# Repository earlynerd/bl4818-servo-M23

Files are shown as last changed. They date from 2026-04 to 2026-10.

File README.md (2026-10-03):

# BL4818 Brushless Servo Musical Actuator

This repository contains the electronics, embedded firmware, host software,
and browser players for a network of brushless servo percussion actuators.
The actuators use modified BL4818 motor-controller hardware, a Nuvoton M2003
microcontroller, hall sensing, and an MT6701 absolute encoder to move a mallet
with controlled timing and force.

The system is in active use: roughly 35 actuators have been built, and the
firmware plus MIDI player/server are working well. The software is much closer
to production-ready than the replication documentation, so this repository
should currently be treated as a proven project under documentation rather
than a turn-key kit.

## Watch and listen

This project makes much more sense with sound. Select the image or the link
below to hear ten actuators perform on a handpan-style tongue drum.

**[▶ Play the 56-second performance video with sound](docs/video/handpan_video_h264.mp4)**

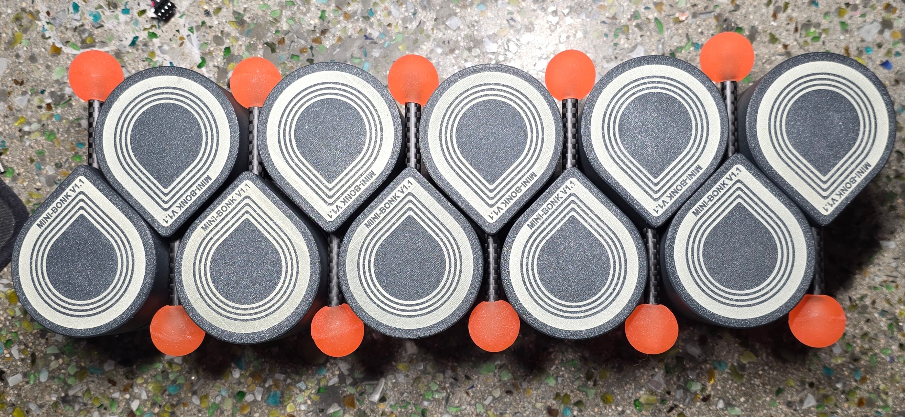
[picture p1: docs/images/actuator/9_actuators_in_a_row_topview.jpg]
Nine completed actuator bodies and mallets viewed from above
 

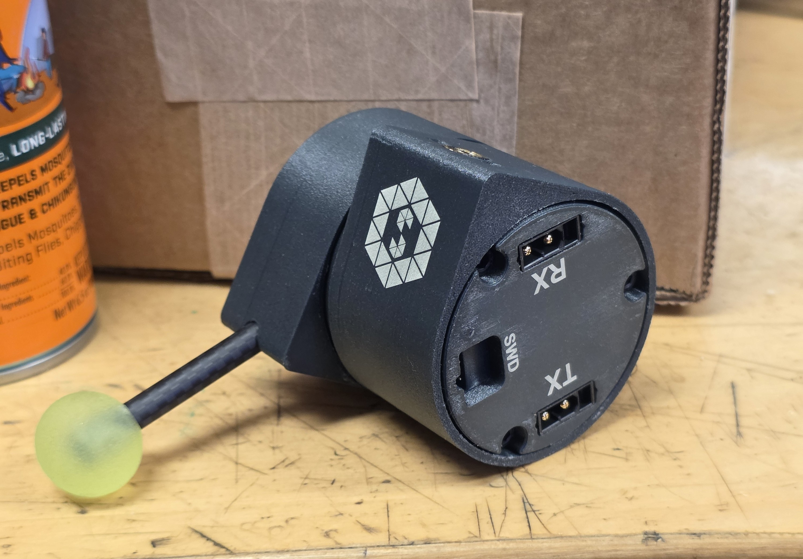
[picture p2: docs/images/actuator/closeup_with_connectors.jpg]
Close-up of an assembled actuator showing RX, TX, and SWD openings
 

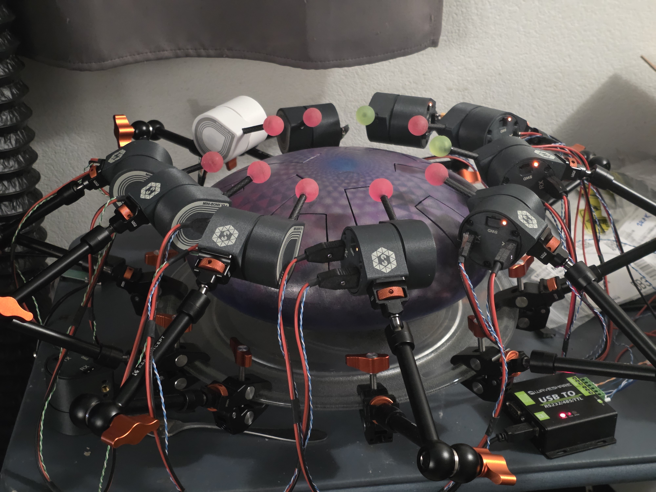
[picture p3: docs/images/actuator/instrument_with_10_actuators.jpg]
Ten brushless servo actuators installed around a tongue drum


Each self-contained actuator packages the modified BL4818 motor controller,
absolute encoder, power/data interface, and mallet mechanism inside the printed
shell. RX and TX connectors allow power and serial data to continue through the
actuator chain, while the recessed SWD port provides programming access.

## System overview

```mermaid
flowchart LR
    MIDI["MIDI file or browser player"] --> HTTP["Python MIDI server"]
    HTTP --> IFACE["USB serial / interface hardware"]
    IFACE --> A0["Actuator 0"]
    A0 --> A1["Actuator 1"]
    A1 --> AN["More actuators"]
    AN --> IFACE
```

The Python server owns the serial port and serves the browser UI. It enumerates
the actuator ring, maps MIDI pitches to actuator addresses, schedules strikes,
compensates for measured mechanical latency, and can build then deploy APROM
updates through the permanent LDROM loaders without releasing the serial port.
The updater and synchronized chord scheduler are hardware-validated on the
14-actuator handpan ring.
Each actuator closes its own
current, velocity, and position loops and runs the homing/strike state machine.
The current protocol uses a four-bit address and supports up to 16 actuators per
ring.

## What is in this repository

- `src/` and `include/`: M2003 bare-metal firmware.
- `scripts/`: ring-bus client, MIDI server, tuning, measurement, and demo tools.
- `player/`: browser-based MIDI player, looper, and tongue-drum player.
- `pcb/`: KiCad electronics plus current mechanical/fabrication exports.
- `mechanical/`: SolidWorks source CAD and STEP exports for the actuator shell,
  mallet holder, and interface-board reference model.
- `docs/`: replication notes, hardware references, debug history, and design notes.
- `protocol.md`: byte-level Ring Bus Protocol v2 specification.
- `midi_server_api.md`: HTTP API for integrations and custom players.

See [Repository map](docs/repository-map.md) for a guided tour.

## Quick software start

The firmware builds on Windows and POSIX hosts, including Raspbian. Its Makefile
expects GNU Make and the Arm GNU toolchain in `PATH`. Initial SWD provisioning
still uses the PowerShell/J-Link scripts and is therefore Windows-oriented.

### 1. Install host dependencies

Install Python 3.10 or newer, then from the repository root run:

```powershell
py -m venv .venv
.\.venv\Scripts\Activate.ps1
py -m pip install -r requirements.txt
```

### 2. Build the firmware

Install `arm-none-eabi-gcc` and GNU Make, then run:

```powershell
make
```

The main output is `build/m2003-motor.bin`. Generate the complete J-Link
payload (application, commit manifest, permanent LDROM loader, and read-only
CONFIG capture) with:

```powershell
powershell -File scripts/build-jlink.ps1
```

Generation does not contact hardware or change CONFIG. The stable Gen1 ring
updater, its recovery evidence, and its completed 14-actuator validation are
documented in [Ring firmware update](docs/firmware-update.md). The LDROM loader
is now maintenance-only; no further Gen1 loader features are planned.

### 3. Flash an actuator

Connect the programmer over SWD and run:

```powershell
powershell -File scripts/flash-jlink.ps1
```

For J-Link V9.58 or newer, use the faster native M2003FC1AE flash loader:

```powershell
powershell -ExecutionPolicy Bypass -File scripts/flash-jlink.ps1 -NativeFlash
```

Add `-SkipBuild` to reuse the generated artifacts, or `-GenerateOnly` to build
them without contacting hardware. Native mode retains the CONFIG preservation,
commit-last manifest, and physical verification described below. Omitting
`-NativeFlash` retains the original per-word programming method.

This standard command first records CONFIG0..2, programs and byte-verifies
APROM, its manifest, and LDROM, then preserves the existing configuration while
selecting LDROM-first boot. It refuses automatic CONFIG changes on a locked or
unexpected security configuration. Disconnect motor power while changing
wiring or attaching the programmer; a servo actuator can move unexpectedly
during bring-up.

### 4. Start the MIDI player

Connect the interface serial port to a powered actuator ring and run:

```powershell
py scripts/ring_midi_server.py -p COM7 --library-dir C:\path\to\midi-library
```

Open <http://localhost:8765/>. Enumerate the ring, home the actuators, and assign
a MIDI pitch to each slot before playing a file. Use the instrument selector
to save and switch named pitch maps and player settings. Profiles are stored locally in
`instruments.json` and are intentionally not committed. An existing
`mapping.json` is imported as the Default profile.

For multiple rings, use one USB adapter per ring (at most 16 actuators each):

```powershell
py scripts/ring_midi_server.py --ring jameson=COM29,10 --ring retuned=COM48,10
```

The player provides a saved-instrument selector for each ring and shared playback
controls. See [multiple-ring setup](docs/host-software.md#multiple-rings-on-one-server)
for profile persistence and slot routing. Firmware updates still use single-ring mode.

For a first hardware check without the browser:

```powershell
py scripts/ring_tool.py -p COM7 enumerate
py scripts/ring_tool.py -p COM7 status 0
```

Run `py scripts/ring_tool.py --help` for the complete command list.

## Documentation

- [Replication guide](docs/replication-guide.md): staged path from hardware to a playing ring.
- [Hardware guide](docs/hardware.md): current BL4818 modification and actuator assembly architecture.
- [Performance video](docs/video/handpan_video_h264.mp4): ten actuators playing with sound.
- [Firmware guide](docs/firmware.md): architecture, build, flash, and module boundaries.
- [Ring firmware update](docs/firmware-update.md): stable LDROM recovery design, flash layout, operation, and validation record.
- [Host software guide](docs/host-software.md): server, browser players, and bench tools.
- [Replication status](docs/replication-status.md): what is reproducible now and what still needs source material.
- [Ring Bus Protocol v2](protocol.md): serial packet and command specification.
- [MIDI server HTTP API](midi_server_api.md): integration API.
- [Design decisions](Decisions.md) and [debug log](DebugLog.md): engineering history.

## Replication status and safety

The repository does not yet contain enough verified information for a new
builder to safely reproduce the complete actuator without assistance. In
particular, power-system limits, connector pinouts, a released BOM, mechanical
assembly dimensions, and a photographed bring-up procedure still need to be
documented. Those gaps are tracked explicitly in
[Replication status](docs/replication-status.md); unknown values are not guessed
in the guides.

This project drives a fast moving mechanism at several amps. Use a current-
limited supply during bring-up, keep hands and instruments clear of the mallet,
provide a physical power disconnect, and test one actuator before assembling a
ring.

## License

No project-wide license has been selected yet. Until one is added, the source
is visible for evaluation but normal open-source reuse permissions have not
been granted. A license should be chosen before presenting the repository as a
fully replicable open-source project; third-party code under `CMSIS/`,
`Library/`, and `RTT/` retains its own notices and terms.

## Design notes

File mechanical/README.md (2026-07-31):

# Mechanical design files

This directory is the maintained source for the actuator enclosure and moving
parts. The current files were created/exported with SolidWorks 2026. Keep native
CAD separate from neutral and print-ready exports so another builder can both
reproduce the proven design and modify it responsibly.

## Directory layout

- `source/`: native SolidWorks assembly/part files and linked components.
- `print-files/`: neutral STEP exports and, when available, revisioned STL or
  3MF files in the verified print orientation.
- Add `drawings/` if dimensioned PDFs, DXFs, or inspection drawings become
  available.

The expected part set includes the three-piece shell, the mallet holder that
slides over the motor bell, and the internal-shaft encoder magnet holder.

## Current file manifest

| File | Role |
| --- | --- |
| `source/actuator.SLDASM` | Top-level actuator assembly |
| `source/base.SLDPRT` | Main motor-side enclosure/base |
| `source/encodercover.SLDPRT` | Rear encoder/interface-board cover |
| `source/interface_pcb.SLDPRT` | Mechanical reference model for the custom PCB |
| `source/mallet_holder.SLDPRT` | Holder that slides over the motor bell |
| `print-files/base.STEP` | AP214 neutral export of the base |
| `print-files/encodercover.STEP` | AP214 neutral export of the encoder cover |
| `print-files/mallet_holder.STEP` | AP214 neutral export of the mallet holder |

The STEP headers identify SolidWorks 2026 and `SwSTEP 2.0`. Before calling this
a complete printable release, add or identify the magnet-holder and remaining
shell component if they are separate parts, verify that the assembly opens
without missing external references, and publish tested STL/3MF orientations or
explicit slicing instructions.

## Release information to include

For each known-good mechanical release, record:

- design/revision name and matching electronics revision;
- native CAD application and version;
- units and export tolerance;
- printer, material, nozzle, layer height, wall count, and infill;
- required supports and print orientation;
- heat-set inserts, screws, bearings, magnets, adhesives, and other hardware;
- critical fits, clearances, and post-processing;
- magnet dimensions, polarity, retention method, and MT6701 air gap;
- mallet/linkage installation and safe travel limits; and
- photographs of the completed assembly.

Do not replace an older known-good export in place. Add a new revision so the
files used for an existing actuator batch remain recoverable.

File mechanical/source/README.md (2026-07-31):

# Editable CAD source

This folder currently contains the SolidWorks 2026 top-level actuator assembly
and native models for the base, encoder cover, interface PCB, and mallet holder.
Add any missing linked components needed to open `actuator.SLDASM` without
suppressed or unresolved references. Future magnet-holder or enclosure parts
should remain alongside the assembly source.

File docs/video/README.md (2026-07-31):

# Demonstration video

`handpan_video_h264.mp4` is a 56-second sound-enabled demonstration of ten
actuators playing the instrument. It was re-encoded with HandBrake and contains
H.264 (`avc1`) video and AAC (`mp4a`) audio markers for broad browser
compatibility. The file is linked prominently from the main README.

The committed MP4 is approximately 36 MB. If a stable GitHub user-attachment or
release-asset URL is added later, the README target can be changed to that URL
to avoid carrying future video revisions in normal Git history.

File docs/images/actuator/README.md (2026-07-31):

# Actuator documentation images

Store the maintained actuator, rework, wiring, and assembly photographs here.

## Current images

| File | Shows |
| --- | --- |
| `closeup_with_connectors.jpg` | Completed actuator and end cap with RX, TX, and SWD openings |
| `9_actuators_in_a_row_topview.jpg` | Nine finished bodies, printed covers, mallet arms, and heads |
| `instrument_with_10_actuators.jpg` | Ten actuators mounted around a tongue drum with cabling and serial interface visible |

New images should use descriptive names such as `actuator-r1-exploded.jpg` or
`bl4818-r1-ina180-rework-closeup.jpg` rather than camera-generated filenames.

Instructional images should have a caption in the referring document that
states the hardware revision, orientation, and what the reader should verify.
Keep original-resolution masters when practical; optimized web copies can be
added separately if repository size becomes a concern.

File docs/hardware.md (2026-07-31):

# Hardware guide

## Current hardware generation

The actuators built so far use a manually modified BL4818 integrated motor-
drive PCB. This is the known working hardware generation. A future board may
replace the complete BL4818 drive PCB as a more drop-in design, but that board
is not the current replication target.

The present retrofit has four main parts:

1. The BL4818 motor and integrated three-phase drive PCB.
2. Manual drive-board modifications for the replacement microcontroller,
   amplified shunt-current measurement, signal routing, and added cabling.
3. A custom encoder/interface PCB carrying the MT6701, local capacitance,
   power/data connectors, and programming connector.
4. A printed three-piece enclosure plus mallet and magnet holders.

## Manual BL4818 drive-board modifications

At a high level, the working modification consists of:

- removing the original onboard microcontroller and installing a Nuvoton M2003;
- mounting an INA180B2 current-shunt amplifier as a bodge over the existing
  shunt area;
- removing selected resistors and shorting selected positions to reroute or
  adapt the relevant signals;
- installing an additional cable assembly alongside the original BL4818 cable.

This list deliberately does not identify pads or resistor designators yet. The
modification is fine-pitch, electrically consequential work on a motor power
stage; it should not be attempted from prose alone. The released instructions
need annotated before/after photographs, reference designators, wire endpoints,
wire gauge, insulation/strain-relief details, and continuity checks.

### Microcontroller

The replacement target is confirmed as the Nuvoton M2003 Cortex-M23. The
firmware, compiler target, linker setup, pin mapping, and hardware documentation
should all use M2003/Cortex-M23 consistently. The exact orderable suffix and
package should be recorded in the released BOM.

## Custom encoder/interface PCB

Both the original BL4818 cable assembly and the added cable assembly plug into
the custom board at the back of the actuator. The board currently contains:

- an MT6701 magnetic absolute encoder;
- ceramic decoupling/bulk capacitors;
- polymer electrolytic bulk capacitors;
- two XT30 2+2 power/data connectors; and
- an SWD programming port.

The pair of XT30 2+2 connectors supports the physical power/data chain through
the actuator. The released schematic and wiring guide still need to define the
exact pin assignments, mating connector orientation, input/output convention,
voltage/current rating, grounding, and behavior of an unpowered actuator.

Editable electronics live under `pcb/`. Once a known-good revision is chosen,
publish a revisioned BOM and fabrication package generated from that source.

Connector end of an assembled actuator showing the RX, TX, and SWD openings

The finished end cap exposes separate RX and TX XT30 2+2 connectors plus a
recessed SWD opening. Final documentation still needs the connector pin
assignments and the SWD adapter/cable mating details.

## Mechanical assembly

The electronics and motor install into a three-piece printed shell:

1. The BL4818 motor bolts to the motor-side shell piece.
2. The mallet holder slides over the motor bell.
3. A magnet holder fits onto the motor shaft. The shaft is internal rather than
   externally exposed, so the holder locates the encoder magnet inside the
   enclosure.
4. The original and added drive-board cables plug into the custom MT6701 board.
5. The custom board is installed behind the motor/magnet assembly.
6. The end cap screws onto the shell and closes the actuator.

The source CAD and printable exports belong under `mechanical/`. The associated
assembly guide should state print material and orientation, support strategy,
fasteners, tolerances, magnet dimensions/polarity, encoder air gap and
alignment, cable routing, mallet position, and installation clearances.

Nine completed actuator bodies and mallets viewed from above

The current mechanical drop includes a SolidWorks 2026 top-level assembly,
native part models for the base, encoder cover, interface-PCB reference, and
mallet holder, plus AP214 STEP exports for the base, encoder cover, and mallet
holder. See `mechanical/README.md` for the file manifest.

## Photograph set needed

Place documentation images under `docs/images/actuator/`. The most useful set
for a new builder is:

- additional fully assembled actuator angles;
- three shell pieces and small mechanical parts laid out separately;
- exploded assembly in physical order;
- stock BL4818 drive board before modification;
- modified drive board, top and bottom, with every rework point annotated;
- close-up of the MCU replacement and INA180B2 bodge;
- original and added cable assemblies with connector orientation visible;
- custom encoder/interface PCB, front and back;
- magnet holder, magnet orientation, and installed encoder air gap;
- SWD connection during flashing; and
- two adjacent actuators showing the power/data daisy chain.

The repository now includes an assembled connector-end close-up, a row of nine
finished actuators, and ten actuators installed around a tongue drum:

Ten actuators installed around a tongue drum

Every image used as an instruction should identify the hardware revision and
viewing orientation. Avoid relying on wire color alone; labels and pin numbers
must agree with the schematic.

## Future direct-replacement drive PCB

The long-term hardware direction is a replacement for the BL4818 integrated
drive PCB that removes the involved donor-board rework. Keep that work in a
clearly named revision/project area and do not overwrite the Gen1 retrofit
instructions. The transition criteria should include equivalent motor-drive
behavior, current sensing, encoder interface, connectors, SWD access, thermal
performance, protection behavior, and a complete bench comparison against a
known-good modified actuator.

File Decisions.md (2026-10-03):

# Decision Log

Forward-facing, append-only record of architectural and behavioral decisions for this project. Read this file at the start of each session — it's more reliable than memory and supersedes any conflicting claims in CLAUDE.md, AGENTS.md, or README.

When a decision is reversed or superseded, append a new entry rather than rewriting the old one.

## 2026-05-14 — Rev2 PCB: switch bus from UART ring to RS485 multi-drop (tentative)

- **Decision:** Rev2 driver PCBA replaces the 5V UART ring (250 kbaud, cut-through forwarding) with RS485 half-duplex multi-drop. XT30 2+2 connectors retained; daisy-chain power + data through devices with a terminator plug on the last open connector. Addresses pre-programmed per device before bus placement and persisted to flash, replacing the ring-walk `ENTER_STORE_FORWARD` / `SET_ADDRESS` enumeration for rev2 nodes. Protocol shifts to master-polls with broadcast packets for command-rate traffic (extends the existing `BROADCAST_DUTY` slot-extraction pattern); feedback is lower rate. Baud target TBD, watch `uart_max` / `uart_rx_overflow_count` telemetry as it goes up from 250 kbaud.
- **Why:** Biggest concrete win is eliminating the cut-through echo write in `UART1_IRQHandler` (`src/app_uart.c:62-66`) — frees CPU on the 24 MHz M2003, which is already at the deadline edge. Differential signaling adds noise headroom (margin, not a current pain point) and removes the ring's downstream-break failure mode. CAN was considered but rejected: M2003 has no CAN peripheral, and rev2 keeps the M2003 because real-world firmware performance has been excellent.
- **Status:** Tentative. Rev2 schematic in progress. Gen1 ring-bus hardware (24 actuators) is in active use today and the gen1 protocol is unchanged on those units.
- **Supersedes:** (initial)
- **Affects:** rev2 PCB design; future `src/app_uart.c`, `src/protocol.c`, `protocol.md` updates for rev2 firmware path.

## 2026-05-14 — Rev2 PCB: RS485 transceiver control on a single GPIO (PB.14)

- **Decision:** PB.14 is the only spare GPIO and is tied to both DE and /RE for half-duplex control. Biased HIGH externally so during MCU reset/SWD the /RE input is deasserted and RO is tri-stated — frees PF.1 (shared with ICE_CLK) for the programmer. DE is also asserted in that state as a consequence. A ~10 kΩ pulldown on the PF.0 → DI net parks the driver at a defined recessive idle when PF.0 is high-Z, so a device under SWD drives a steady idle rather than spraying SWD edges or random levels onto the bus.
- **Why:** PF.0/PF.1 are shared between UART1 and ICE_DAT/ICE_CLK, so the transceiver's RO output cannot fight the programmer on PF.1. Biasing PB.14 high satisfies that constraint with the one available pin. Full tri-state of the transceiver during reset would need a second GPIO (none available) or a transceiver with a dedicated enable pin — not pursued.
- **Accepted tradeoff:** A device under SWD pauses bus traffic for the duration of the programming session (its transceiver dominates the differential pair driving recessive idle). Acceptable because (a) not safety-critical, (b) workflow programs devices off-bus before placement; no live-bus reflash use case.
- **Status:** Tentative, follows from the rev2 bus topology decision above.
- **Supersedes:** (initial)
- **Affects:** rev2 PCB schematic — RS485 transceiver wiring, PB.14 net, PF.0/DI pulldown.

## 2026-05-28 — Server-side playback dispatch; one `Player` for chimes + songs

- **Decision:** Scheduled playback is dispatched from the Python server, not the browser. Browser POSTs the full schedule once at play-start to `POST /api/play`; a single worker thread inside `Player` (`scripts/ring_midi_server.py`) fires each strike from `time.monotonic()` + `Event.wait()`. Live tweaks (master mA, mute set) go through `POST /api/play/update` and apply on the next strike. `POST /api/play/stop` stops the worker without disabling motors. The previous `MotifPlayer` (chime integrations) and the never-shipped browser-side song dispatcher are unified into one `Player` class — the `/api/play` handler auto-detects pitch-style vs canonical event input and translates the former via `motif_events_to_canonical()`. `/api/motif` is removed.
- **Why:** Browser-side per-event `setTimeout` + per-strike `fetch /api/strike` sounded fine over localhost (~3 ms network, ~2.5 ms scheduler jitter) but failed audibly over WiFi (57 ms mean network, 1990 ms max → 2 seconds of silence followed by a flurry of catch-up strikes). Any browser tab hiccup or WiFi stall queued per-strike POSTs that arrived in a clump. Server-side dispatch puts the dispatcher next to the hardware so the variable-latency link can't affect beat timing — the schedule is already in the server's hands.
- **Accepted tradeoffs:** (1) Per-slot trim and velocity-floor are now frozen at schedule build; only master mA and the mute set survive as live tweaks (matches the user's stated need; full live parity would require recomputing currents server-side from raw velocity, duplicating the browser's pipeline). (2) The browser popup's pipeline-timing metrics (sched jitter, network, server total, lock wait, serial RTT) and the per-slot residual stats no longer update during server-dispatched playback — those measurements live in `strikeAsync` which is bypassed on this path. They still work for keyboard test taps. Closing that gap (server exposes per-slot residual; browser polls during playback) is deferred.
- **Supersedes:** the implicit browser-dispatch architecture in `play()` and `MotifPlayer` (now replaced by `Player`). Builds on [[feedback_timing_compensation_minimal]] — that was the *prediction* problem; this is the *dispatch* problem.
- **Affects:** `scripts/ring_midi_server.py` (new `Player`; deleted `MotifPlayer`/`SongPlayer`; new endpoints `/api/play`, `/api/play/stop`, `/api/play/update`; removed `/api/motif`); `player/midi_player.html` (`play()` and `stopPlayback()` rewritten; master-slider live-update hook); `scripts/chime_demo.py` (point at `/api/play`); `midi_server_api.md` (endpoint docs).

## 2026-05-29 — Player exposes residual + timing stats; popup polls during playback

- **Decision:** `Player.status()` now includes `residual_stats` (per-address: `last`/`sum`/`sumSq`/`n`/`maxAbs`) and `timing_stats` (`lock_wait_ms` + `serial_rtt_ms`, same bag shape). Player tracks residual = `trigger_to_impact_ms − comp_ms_at_strike_time`, holding the previous prediction per address so the next ACK's metric attributes to the right strike (same one-strike lag pattern as `LatencyTracker._fold_metrics_into_ema`). Browser polls `GET /api/play` every 250 ms while `S.playing` and routes the popup's Residual, lock_wait, and serial_rtt rows through the server's view; sched_jitter and network rows hold their pre-playback session totals (those metrics don't exist on the server-dispatch path — no setTimeout, no per-strike fetch).
- **Why:** Closes the "deferred" gap explicitly noted in the previous entry. Without this, the per-strike metrics we'd added one session earlier went silent during server-dispatched playback — invisible exactly when they were most useful. Stats accumulate across plays; only a server restart resets them, so the popup's `n=` count keeps growing as a useful sample size.
- **Status:** Completes the deferred item in the 2026-05-28 entry. Does not supersede that decision — the architecture is unchanged; this is the visibility layer on top of it.
- **Supersedes:** (none — completes deferred work from 2026-05-28).
- **Affects:** `scripts/ring_midi_server.py` (`Player.residual_stats` / `timing_stats` / `_last_prediction_ms` / `_fold_stat`; `status()` payload includes the new bags); `player/midi_player.html` (`startPlayPolling` / `stopPlayPolling`; `refreshCfgTiming` reads server bags when `S.playing`).

## 2026-06-04 — Status LED polarity tracks autodetected CSn polarity

- **Decision:** The indicator no longer assumes "PB1 high = LED lit". It maps each pattern's logical lit/dark through the autodetected CSn assert level (`encoder_get_csn_polarity()`) via a new `pin_level_for()` helper: lit → assert level, dark → de-assert level. The LED lights and CSn asserts on the same electrical event, so "lit" must follow the same per-board polarity the encoder already learns. `indicator_get_csn_level()` now publishes the *physical* PB1 level (was logical).
- **Why:** PB1 is shared between SSI CSn and the status LED, and the LED lights at whichever level asserts CSn. The old fixed `PIN_SSI_CSN = level` only matched the modchip variant (assert=1); on FET-inverting / CSn-active-low boards (assert=0) every pattern read inverted. Behavior is byte-identical on assert=1 boards (identity map) and inverted-as-intended on assert=0 boards.
- **Caveat:** Mapping assumes the LED lights at the *assert* level. Consistent with the symptom (active-low boards read inverted) but unverified on the bench at time of writing — if still inverted on an assert=0 unit, flip the ternary in `pin_level_for()`.
- **Supersedes:** (initial) — first polarity-aware behavior for the indicator; builds on the existing CSn autodetect (`encoder_autodetect_csn_polarity`).
- **Affects:** `src/indicator.c` (`pin_level_for`, `indicator_init`, `indicator_tick`), `include/indicator.h` (module doc + `indicator_get_csn_level` contract).

## 2026-06-04 — Ring bus link-health instrumentation + browser panel

- **Decision:** The bridge now accumulates per-address ring-link health (`BusHealth`: RTT sum/sumSq/max/last in µs over successful transactions, plus `timeouts` / `crc_errors` / `errors` counts and `last_error`). Fed at the bridge chokepoints that touch the bus — `strike()` (wrapped to record the drop on the exception it already lets propagate) and the per-address `query_strike` path shared by `status()` / `pitches()` / the new `probe_bus()`. New endpoints: `GET /api/bus-health` (snapshot), `POST /api/bus-health/probe` (one active query round, returns snapshot), `POST /api/bus-health/reset`. The browser player gained a live "Bus Health" sidebar panel that polls every 1 s and, while idle, actively probes once a second (auto-suspends during playback — live strikes feed the same counters then); rows show per-device `mean ± σ` / max RTT and a drop-rate, colored red on CRC/≥5% drops, amber on occasional drops.
- **Why:** Diagnosing intermittent wiring (flaky connectors on the daisy-chain) had no observable signal — dropped strike replies were caught in the playback worker and silently skipped (`Player._run`), and `serial_rtt` was only folded during song playback. This surfaces "packets disappear" (timeouts), "come back mangled" (CRC = bus noise), and "take longer than expected" (RTT spread) per device, live.
- **Accepted tradeoffs:** (1) Counts are cumulative since reset (mirrors the existing `timing_stats`/`residual_stats` bags) — no rolling window; the reset button covers the wiggle-a-wire workflow. (2) Active probe holds the ring lock per-address (not around the whole sweep) to cap the latency a concurrent keyboard tap can incur to one query. (3) Latency spread is shown numerically but not colored — sub-ms RTTs see large *relative* OS/serial jitter on a healthy bus, so coloring on σ would cry wolf.
- **Supersedes:** (initial) — first link-health visibility. Builds on the server-side dispatch + stats-polling pattern from the 2026-05-28/05-29 entries.
- **Affects:** `scripts/ring_midi_server.py` (`BusHealth`; `Bridge.health` / `_record_bus_exc` / `_query_strike_timed` / `probe_bus`; instrumented `strike` / `status` / `pitches`; 3 endpoints; imports `RingCRCError`), `player/midi_player.html` (Bus Health panel + `renderBusHealth` / `busHealthTick` / monitor wiring), `midi_server_api.md` (endpoint docs).

## 2026-06-09 — Dead-strike articulation: STRIKE_EX command + MUTING state

- **Decision:** New `STRIKE_EX` (0x1A): `[type] [current_hi] [current_lo] [param_hi] [param_lo]`. Type 0 = normal (identical to `STRIKE`), type 1 = dead strike — drive/coast unchanged, then at detected impact the firmware enters a new `STRIKE_MUTING` state (wire value 6): velocity mode setpoint 0 brakes the rebound (braking current self-scales via the 1500 Hz velocity PI; bumpless because `motor_set_mode` seeds the PI at zero error), then a small toward-drum torque presses the mallet into the surface for the commanded dwell (`param`, ms; 0 = 150 default, clamped to 1000), then the normal catch. Articulation is per-command, not device state. New `SET_STRIKE_PARAM` tunables: `MUTE_BRAKE_MS` 0x04 (default 30) and `MUTE_PRESS_MA` 0x05 (default 250; 0 = velocity-hold for whole dwell). New timing flag 0x0200 = dead strike; rebound fields never become valid for dead strikes. Coast-timeout without detected impact still enters MUTING (gentle press = damp-like) with the 0x0020 timeout flag. Retrigger during MUTING rejects `NOT_READY`; `STRIKE_CANCEL` aborts the mute early.
- **Why:** Mute articulation ("dead strikes") needs the mallet to stay in contact past impact, overcoming the rubber tip's rebound to prevent bounce-chatter. Velocity-0 braking was chosen over a fixed torque surge because it scales braking current to actual rebound energy with no per-strike tunable. Per-command type (vs a sticky mode) follows the per-request-over-global-state rule. New subcmd (vs widening `STRIKE`) so gen1 firmware rejects it loudly with `INVALID_ARGUMENT` instead of silently playing the wrong articulation.
- **Accepted tradeoffs:** (1) `MUTE_BRAKE_MS`/`MUTE_PRESS_MA` are not persisted by `SAVE_SETTINGS` (reset to defaults at boot) — defer flash-layout change until bench tuning settles values. (2) `QUERY_STRIKE` reply does not report the new tunables (wire layout unchanged). (3) Brake/press handoff quality on the rubber tip is unverified on the bench at time of writing; if the velocity loop chatters against the compliant contact, fall back to torque-surge entry or retune brake duration.
- **Supersedes:** (initial) — first articulation beyond the single strike type.
- **Affects:** `src/strike.c` / `include/strike.h` (`STRIKE_MUTING`, `strike_trigger_ex`, mute tunables, `STRIKE_TIMING_DEAD`), `src/protocol.c` (`SUBCMD_STRIKE_EX`, param ids 0x04/0x05), `include/m2003_config.h` (`STRIKE_MUTE_*` defaults), `protocol.md`, `scripts/ring_bus.py` (`strike_ex`, consts), `scripts/ring_tool.py` (`strike --dead --mute-ms`, new `set-strike-param` choices).

## 2026-06-10 — Dead-strike mute entry is position-armed, not velocity-zero-cross

- **Decision:** The velocity-0 brake for dead strikes now trips inside the motor layer on the raw encoder position crossing of the learned drum surface, via a two-stage armed trigger (`motor_arm_coast_then_brake`: coast at the coast point, brake at `drum_position − drum_dir × MUTE_ENGAGE_OFFSET`), checked at the encoder sampling cadence like the existing coast arm. New `SET_STRIKE_PARAM` id `MUTE_ENGAGE_OFFSET` 0x06 (signed counts; default 0 = at the surface; positive = before it, negative = past it). The filtered-velocity zero-cross remains only as the stalled-short fallback; the coast-timeout damp path is unchanged. `strike_tick` records coast/impact timestamps best-effort (≤ one 500 Hz tick late) when the brake trips between ticks — the brake action itself is not delayed.
- **Why:** Bench showed double hits: the filtered-velocity zero-cross (EMA group delay) plus the 500 Hz strike-tick quantization engaged the brake after the rubber tip had already launched the rebound, so the press phase re-seated the mallet from a hover gap — an audible second tap. Raw-position arming engages the brake within one encoder sample of contact, while the ball is still compressing. See DebugLog.md 2026-06-10.
- **Supersedes:** the "at the firmware's impact detection (velocity zero-cross)" entry mechanism in the 2026-06-09 dead-strike entry; the rest of that decision stands.
- **Affects:** `src/motor.c` / `include/motor.h` (`motor_arm_coast_then_brake`, `motor_is_brake_engaged`, brake stage in the coast-trip handler, `brake_trip_pos` in `motor_shift_position_reference`), `src/strike.c` (`on_brake_engaged` / `enter_muting` split, dead-strike arming in `begin_strike`, `mute_engage_offset`), `src/protocol.c` (param 0x06), `include/m2003_config.h`, `protocol.md`, `scripts/ring_bus.py`, `scripts/ring_tool.py`.

## 2026-06-12 — Library browser: subfolders, favorites/ratings, jukebox controls

- **Decision:** The MIDI library browser is now a drill-down file browser over a *recursive* `--library-dir`. `GET /api/library` recurses (`rglob`) and returns each file as `{path, name, dir, size, mtime}` (POSIX-relative) plus a bundled `meta` map; the old flat `{name, size}` is superseded (the `name` field is retained, so the change is additive for any other reader). `GET`/`POST /api/library/<path>` now accept nested subpaths — the `name == Path(name).name` rejection is replaced by `Handler._resolve_library_path()` (rejects absolute / `..`, then a `resolve().relative_to(lib)` containment check is the authoritative escape guard); POST creates parent dirs so "Save current" lands in the folder being browsed. Favorites + 0–5 ratings (plus `play_count` / `last_played`) persist in **`.midi_library.json` inside the library folder** (keyed by path), read/merged/written under `Handler._meta_lock` since the server is a `ThreadingHTTPServer`; new `GET`/`POST /api/library-meta`. Browser side (`player/midi_player.html`): folder tree + breadcrumb derived from the flat list, a search box that flattens across all folders, a ★-only filter, a sort dropdown (name/rating/recent/plays), per-row ♥ + ★ controls, and jukebox controls — Shuffle, Autoplay-next, and Prev/Next buttons. The current view *is* the play queue.
- **Why:** A flat list doesn't scale as the collection grows, and there was no way to favorite, rate, or shuffle. Storing metadata in the library folder (the user's explicit choice) makes it shared across browsers/machines and travels with the collection — the same rationale as `mapping.json` being server-side, not per-browser localStorage. Only `midi_player.html` consumes `/api/library` (`looper.html` has no browser), so the response-shape change is low-risk.
- **Accepted tradeoffs:** (1) Autoplay **wraps** at end-of-list (jukebox "repeat all") rather than stopping — toggle autoplay off to halt. (2) Stale meta keys for deleted files are left in place (harmless; no prune step). (3) Play-count bumps in the client `play()` start path, so it counts real plays, not previews — but that path needs a live bridge, so it's the one piece not exercised by the headless browser test (the server-side `bump_play` merge itself is covered). (4) Autoplay-next distinguishes natural end from manual stop via a new `reason` arg on `stopPlayback("ended"|"user")` — only the teardown timer and the poll's `!playing` branch pass `"ended"`.
- **Supersedes:** the flat, single-folder library listing and the no-path-separator filename guard. Builds on the server-side dispatch architecture (2026-05-28) — autoplay hooks the existing `stopPlayback` natural-end signal.
- **Affects:** `scripts/ring_midi_server.py` (recursive `/api/library`; `_resolve_library_path` / `_library_meta_path` / `load_library_meta` / `save_library_meta` / `LIBRARY_META_NAME` / `_meta_lock`; new `/api/library-meta` GET+POST; subpath-aware library GET/POST; `PurePosixPath` import; module docstring + `--library-dir` help), `player/midi_player.html` (library panel markup + CSS, the rewritten library closure, Prev/Next buttons, `stopPlayback(reason)` + the two natural-end call sites, `libraryNotePlayed` hook in `play()`).

## 2026-07-31 — Document the proven actuator as a manual BL4818 retrofit

- **Decision:** The current reproducible hardware target is the proven manual BL4818 drive-board retrofit; a drop-in replacement for the complete integrated drive PCB remains a future hardware revision and must be documented separately.
- **Why:** The working actuators replace the stock MCU, add an INA180B2 shunt amplifier, modify resistor links, add a cable assembly, and connect both cable assemblies to a custom MT6701/power/interface board inside the printed shell. Replication documentation must describe the hardware that has actually been built before presenting the cleaner future board.
- **Supersedes:** (initial)
- **Affects:** `docs/hardware.md`, `docs/replication-guide.md`, `docs/replication-status.md`, `pcb/`, and `mechanical/`.

## 2026-07-31 — Gen1 STOP resets strike state; housekeeping follows SysTick

- **Decision:** Gen1 `STOP` is a coordinated actuator stop, not only a motor-mode change. It disarms coast/brake triggers, disables motor drive, returns the strike state machine to idle, and clears the runtime `homed` flag so a new `STRIKE_HOME` must complete before another strike. `STRIKE_HOME` now gives a truthful compact ACK (`OK`, busy/not-ready, fault, or disabled/invalid) when ACK mode is requested. Strike, indicator, and protocol-timeout housekeeping are scheduled from the fixed SysTick/control cadence rather than elapsed PWM/ADC samples, so they continue to run while PWM and ADC triggering are stopped.
- **Why:** A motor-only stop could leave the strike state machine active while also freezing the sample-derived housekeeping that would unwind it. That produced stale state and misleading command success after a stop. The coordinated contract makes the disabled state explicit and recoverable through re-homing without imposing tighter validation on tuning parameters.
- **Supersedes:** the implicit behavior where `STOP` and zero-duty only called `motor_stop()` while preserving strike/homed state; no prior documented protocol contract is otherwise changed.
- **Affects:** `src/main.c`, `include/sched_util.h`, `src/protocol.c`, `src/strike.c`, `include/strike.h`, `protocol.md`, `scripts/ring_midi_server.py`, `midi_server_api.md`.

## 2026-07-31 — Gen1 chord dispatch pipelines addressed strikes far-to-near

- **Decision:** The server groups playback events whose compensated trigger deadlines are within 1 ms and target unique actuators, then writes their existing addressed `STRIKE` frames as one farthest-address-first serial train. It waits for compact ACKs only after every command has been written and matches replies by address. This adds no broadcast command and does not change Gen1's one-direction, byte-level cut-through forwarding; normal isolated strikes retain `ACK_TIMED` timing feedback.
- **Why:** Sequential request/ACK round trips add host latency between chord notes even though the point-to-point links themselves forward each byte immediately. Farthest-first ordering ensures a farther device's downstream reply cannot get in front of a command still intended for a nearer device. The result removes avoidable millisecond-scale host skew while keeping rejection visibility; remaining on-wire skew is only the short frame serialization/cut-through interval and was already below the audible problem threshold.
- **Accepted tradeoff:** Chord bursts use plain ACKs, so those strikes do not return the previous strike's timing snapshot inline. Timing learning continues through isolated `ACK_TIMED` strikes and explicit timing polls.
- **Supersedes:** only the per-note wait-for-ACK dispatch detail of the 2026-05-28 server-side playback decision; the single `Player`, server-side schedule ownership, and latency-compensation architecture remain in force. The tentative Rev2 RS485 direction is unchanged.
- **Affects:** `scripts/ring_bus.py`, `scripts/ring_midi_server.py`, `player/midi_player.html`, `midi_server_api.md`, `tests/test_ring_playback.py`.

## 2026-08-01 — Gen1 firmware updates use a permanent LDROM recovery loader

- **Decision:** Existing Gen1 actuators will receive a one-time SWD provisioned, 4 KB LDROM loader that runs before APROM, keeps byte-level UART cut-through forwarding, and updates one addressed device at a time. APROM is divided into application `0x0000..0x79FF`, a commit-last manifest page at `0x7A00..0x7BFF`, and the unchanged two-page settings journal at `0x7C00..0x7FFF`. The loader erases the manifest before any application page and writes it only after exact-length CRC-32 verification; an invalid or interrupted image therefore remains recoverable in LDROM. Version 1 cannot update LDROM, configuration words, or persistent settings over the ring.
- **Why:** Manually connecting a programmer to every installed actuator is costly, while the M2003 provides enough independent LDROM for a recovery anchor. A manifest-last transaction gives power-loss recovery without an A/B application, which cannot fit in 32 KB. Keeping updates sequential preserves clear per-device retry and failure attribution on the one-direction point-to-point ring.
- **Bench gate:** Do not encode or write CONFIG0/CBS yet. First read the fleet configuration and verify LDROM-first IAP plus system-reset behavior on one restrained actuator; the exact value remains a measured provisioning input until then.
- **Supersedes:** the APROM-only/manual J-Link update workflow for provisioned Gen1 devices. Initial loader installation still requires SWD. The tentative Rev2 RS485 decisions are unchanged.
- **Affects:** `m2003.ld`, `include/firmware_image.h`, `ldrom/`, `src/protocol.c`, `scripts/ring_bootload.py`, provisioning scripts, `protocol.md`, and `docs/firmware-update.md`.

## 2026-08-01 — Standard J-Link flashing always installs the complete firmware stack

- **Decision:** `build-jlink.ps1` and `flash-jlink.ps1` are the sole supported J-Link path and always build, program, and verify APROM, the commit manifest, and LDROM; they never write CONFIG. There is no separate app-only or provisioning entry point.
- **Why:** The temporary split left the familiar flash command installing a loader-aware application without the loader, which was surprising and produced an actuator that could not safely accept `ENTER_BOOTLOADER`.
- **Supersedes:** the temporary app-only `flash-jlink.ps1` plus separately named LDROM provisioning workflow created during the 2026-08-01 loader implementation.
- **Affects:** `Makefile`, `scripts/build-jlink.ps1`, `scripts/flash-jlink.ps1`, J-Link artifacts, `README.md`, `docs/firmware.md`, and `docs/firmware-update.md`.

## 2026-08-01 — Gen1 SWD and ring UART are mutually exclusive bench connections

- **Decision:** Gen1 bootloader diagnostics must not assume simultaneous SWD and UART access: the J-Link SWD connection and UART ring adapter use the same two MCU pins and can only be connected one at a time.
- **Why:** Bench testing confirmed that attaching J-Link while observing the UART boot handoff is physically impossible on the existing actuator hardware. Diagnostics must use UART-visible state, retained evidence, or a sequential cable handoff.
- **Supersedes:** the simultaneous J-Link/UART diagnostic proposed during the first LDROM bench test; no firmware architecture decision is otherwise changed.
- **Affects:** Gen1 bootloader bench procedure, `docs/firmware-update.md`, and future diagnostic instrumentation.

## 2026-08-01 — LDROM residence is indicated by a solid onboard LED

- **Decision:** The Gen1 LDROM loader configures shared PB1 as GPIO output and holds it low for its entire residency, lighting the onboard LED solid on the current N-FET retrofit; the loader never accesses the encoder while holding its shared CSn pin.
- **Why:** SWD and UART cannot be attached together, so loader entry needs an immediate local indication that is independent of either diagnostic connection.
- **Supersedes:** the proposed fast-blink loader indicator; the application LED patterns are unchanged.
- **Affects:** `ldrom/platform.c`, `docs/firmware-update.md`, and `protocol.md`.

## 2026-08-01 — LDROM boot-intercept window is one second

- **Decision:** A valid application reached through LDROM without a valid retained boot request remains in the loader for one second before returning to APROM. PB1 remains solid for that full interval, and `STAY_IN_BOOTLOADER` may hold it resident.
- **Why:** The former 100 ms interval was too brief to distinguish from the application's several normal LED flashes during UART-only bench diagnosis. One second makes loader execution unambiguous and gives the recovery host a practical acquisition window without adding another diagnostic-only code path.
- **Supersedes:** the initial 100 ms provisional boot-intercept value.
- **Affects:** `ldrom/bl_internal.h`, `protocol.md`, and `docs/firmware-update.md`.

## 2026-08-01 — Standard Gen1 provisioning selects LDROM-first boot

- **Decision:** The sole supported J-Link command reads and records CONFIG0..2 before any write, programs and verifies APROM/manifest/LDROM, then clears only CONFIG0.CBS (bit 7) so reset and cold power enter LDROM. The wrapper refuses a locked or unexpected CONFIG2 security state, uses the vendor CONFIG erase procedure, verifies the erased state, restores captured CONFIG1 first, commits the preserved CONFIG0 with CBS cleared last, and verifies all three words. Configuration remains inaccessible over the ring.
- **Why:** The restrained actuator measured `CONFIG0=FFFFFFFF`, so CBS selected direct APROM boot. Bench tests proved that the runtime BS write plus system reset still returned to APROM. LDROM-first CBS is therefore required for the permanent recovery invariant: an invalid or interrupted APROM image must reach the independent loader without SWD.
- **Supersedes:** the CONFIG-write prohibition and open CONFIG/CBS bench gate in the earlier permanent-loader decision, plus the “never writes CONFIG” clause of the standard J-Link-path decision. The one public flash path and its APROM/manifest/LDROM verification contract remain unchanged.
- **Affects:** `scripts/flash-jlink.ps1`, `scripts/m2003_configure_ldrom.py`, `scripts/make_provision_jlink.py`, provisioning tests, `README.md`, `docs/firmware.md`, and `docs/firmware-update.md`.

## 2026-08-01 — LDROM starts APROM only through system reset

- **Decision:** The loader never directly calls an APROM reset vector. After validation and UART drain it selects APROM in the runtime BS bit and requests a system reset; APROM's `Reset_Handler` immediately re-arms LDROM as the next-reset destination before normal initialization.
- **Why:** A direct IAP branch must reconstruct reset-state CPU and peripheral context and the first implementation left interrupts masked, producing a repeat watchdog/reset cycle. The M2003 system reset preserves the software BS selection, so a clean APROM reset followed by immediate LDROM re-arming is both simpler and recovery-safe.
- **Supersedes:** the resetless vector-remap-and-jump handoff in “Gen1 firmware updates use a permanent LDROM recovery loader.”
- **Affects:** `ldrom/main.c`, `src/startup_m2003.c`, `src/boot_control.c`, `protocol.md`, and `docs/firmware-update.md`.

## 2026-08-01 — LDROM indicator drives PB1 high on the bench retrofit

- **Decision:** While resident, the Gen1 LDROM loader holds shared PB1 high to light the onboard status LED solid; it still never accesses the encoder.
- **Why:** A UART-confirmed loader hold left the LED dark with PB1 low, while the application's brief high-level indication was visible, proving the assumed polarity was reversed on the restrained actuator.
- **Supersedes:** the PB1-low polarity in “LDROM residence is indicated by a solid onboard LED.”
- **Affects:** `ldrom/platform.c`, `protocol.md`, and `docs/firmware-update.md`.

## 2026-08-02 — APROM/LDROM handoffs verify both VECMAP and boot source

- **Decision:** Both software handoffs follow the M2003 vendor ISP sequence: with interrupts masked, issue and verify `VECMAP` for the destination, select and verify the matching runtime boot source, then request a system reset. The application still re-arms LDROM early by changing only the next-reset boot source; it does not remap vectors while APROM is running. Loader protocol 2 appends the entry `SYS.RSTSTS`, `FMC.ISPCTL`, and `FMC.ISPSTS` snapshots to `GET_INFO` so the result can be diagnosed over UART.
- **Why:** Bench behavior showed that changing the boot-source bit alone did not produce a reliable, observable transition, while the manufacturer's M2003 ISP examples explicitly pair destination `VECMAP`, boot selection, and system reset. Gen1 shares its SWD and UART pins, so retained UART-readable evidence is required to distinguish a clean system-reset handoff from a watchdog return or vector-map failure.
- **Accepted tradeoff:** Protocol 2 leaves only 16 bytes free in the 4 KB LDROM image. Further loader features must recover code space before being added.
- **Supersedes:** the handoff mechanism detail in “LDROM starts APROM only through system reset”; the no-direct-branch rule, true reset entry, and early LDROM re-arm remain unchanged.
- **Affects:** `ldrom/main.c`, `ldrom/flash.c`, `ldrom/protocol.c`, `src/boot_control.c`, `scripts/ring_bootload.py`, `protocol.md`, `docs/firmware.md`, and `docs/firmware-update.md`.

## 2026-08-02 — J-Link verifies the APROM vector page through physical FMC reads

- **Decision:** The standard `flash-jlink.ps1` path programs once, then runs a separate read-only verification script. It reconstructs APROM bytes `0x0000..0x01FF` from physical FMC read commands and joins them with a direct debugger read of APROM above `0x0200`; the manifest and LDROM remain direct physical reads. All three images are compared byte-for-byte before any CONFIG update is committed.
- **Why:** In provisioned LDROM-first mode, the debugger's CPU-address read at zero observes the active LDROM vector alias rather than physical APROM. The prior direct `savebin 0` check therefore reported a repeatable false APROM mismatch at reset-vector offset `+0x4` even though programming succeeded.
- **Supersedes:** direct debugger verification of the full APROM image beginning at CPU address zero. The one public flash command and byte-for-byte verification requirement remain unchanged.
- **Affects:** `scripts/make_provision_jlink.py`, `scripts/flash-jlink.ps1`, `tests/test_provision_jlink.py`, `docs/firmware.md`, and `docs/firmware-update.md`.

## 2026-08-02 — Ring enumeration waits for returned transition frames

- **Decision:** The host no longer uses fixed sleeps to change ring forwarding modes. It waits for the returned `ENTER_STORE_FORWARD` frame, accepts only a nonzero bounded `SET_ADDRESS` result while skipping delayed/seed echoes, then waits for the returned `ENTER_CUT_THROUGH` frame before declaring enumeration complete.
- **Why:** Immediate re-enumeration after `RUN_APROM` exposed USB-UART latency beyond the old 10 ms flush window; the delayed `0x01` echo was mistaken for the address result even though the application had started correctly.
- **Supersedes:** fixed 10 ms/2 ms enumeration settling delays and single-frame `SET_ADDRESS` reply handling.
- **Affects:** `scripts/ring_bus.py`, all host tools using `RingClientV2.enumerate()`, `tests/test_ring_playback.py`, and `protocol.md`.

## 2026-08-02 — Protocol 3 broadcasts only the loader data phase

- **Decision:** Protocol-3 loaders accept tail-addressed ring-wide `BEGIN_IMAGE`, `ERASE_PAGE`, and `WRITE_CHUNK` commands; only the farthest loader replies for pacing, after which the host verifies, repairs, commits, and starts every actuator individually. Sequential `--all` remains supported.
- **Why:** Every actuator receives the same cut-through image bytes, so transmitting them once removes fleet-size multiplication without allowing simultaneous replies or weakening per-device CRC and manifest-last recovery.
- **Accepted tradeoff:** A stopped broadcast can leave the whole participating ring resident in LDROM. A tableless non-cloned CRC-32 makes the feature fit at 4,092 / 4,096 bytes, leaving 4 bytes of LDROM margin.
- **Supersedes:** the sequential-only data-transfer detail in “Gen1 firmware updates use a permanent LDROM recovery loader” and the 16-byte protocol-2 margin in “APROM/LDROM handoffs verify both VECMAP and boot source.”
- **Affects:** `ldrom/crc32.c`, `ldrom/protocol.c`, `scripts/ring_bootload.py`, `tests/test_ring_bootload.py`, `protocol.md`, `docs/firmware-update.md`, and `docs/host-software.md`.

## 2026-08-02 — MIDI server builds and updates a frozen firmware artifact in-process

- **Decision:** The browser Firmware panel uses two explicit actions: the MIDI server runs a fixed `make` in its checkout and freezes the validated application `.bin` plus CRC/version/source identity, then a separately confirmed Update action reuses the server's existing `RingClientV2` connection for the protocol-3 full-ring transaction under an exclusive maintenance flag and ring lock. The first version does not run Git operations or accept uploaded ELF/binary files.
- **Why:** The MIDI server already owns the serial port, so launching the standalone bootloader CLI would collide with its COM handle. A frozen artifact makes the operator-confirmed CRC authoritative, while the build/update split keeps compilation non-destructive and prevents an accidental one-click source-to-fleet deployment.
- **Supersedes:** the requirement to stop the MIDI server for every ring update when using the browser/server path; standalone `ring_bootload.py` still requires exclusive ownership and therefore still requires the server to be stopped.
- **Affects:** `scripts/ring_bootload.py`, `scripts/ring_midi_server.py`, `player/midi_player.html`, `tests/test_ring_bootload.py`, `tests/test_ring_playback.py`, `midi_server_api.md`, `README.md`, `docs/host-software.md`, and `docs/firmware-update.md`.

## 2026-08-03 — Firmware Makefile supports Windows and POSIX hosts

- **Decision:** GNU Make selects Windows or POSIX directory/cleanup commands and defaults to `py` or `python3` respectively, while keeping tool variables overrideable. The MIDI server also writes captured failed-build output to its shell as well as retaining it for the browser.
- **Why:** The instrument server runs Raspbian; the previous Windows command used by object rules failed with Make exit 2 before compilation, and output capture hid the underlying error from the server shell.
- **Supersedes:** the Windows-only build-host assumption in the README and firmware guide. PowerShell/J-Link SWD provisioning remains Windows-oriented.
- **Affects:** `Makefile`, `scripts/ring_midi_server.py`, `README.md`, `docs/firmware.md`, `docs/host-software.md`, and `midi_server_api.md`.

## 2026-08-03 — Playback chords are MIDI-time groups and do not wait for replies

- **Decision:** Only playback events with the same requested MIDI impact time may share a chord train; members with compensated transmit deadlines within 1 ms are written farthest-address first using reply mode `NONE`. Isolated notes retain `ACK_TIMED`, and the browser waits for authoritative server completion instead of canceling at nominal duration plus 500 ms.
- **Why:** A 14-actuator bench run lost 13 burst ACKs, reached 508.7 ms serial waits, attempted only 212 of 278 scheduled notes, and was then canceled by the browser timer. Reply visibility cannot be allowed to block or terminate real-time playback, and similar compensated transmission times do not imply the notes are a chord.
- **Supersedes:** the 2026-07-31 chord-dispatch rules that grouped solely by compensated deadline and collected compact ACKs after each train; farthest-first command ordering remains.
- **Affects:** `scripts/ring_bus.py`, `scripts/ring_midi_server.py`, `player/midi_player.html`, `tests/test_ring_playback.py`, `protocol.md`, `midi_server_api.md`, and `docs/host-software.md`.

## 2026-08-03 — Gen1 updater and chord scheduler are hardware-validated

- **Decision:** Declare the Gen1 LDROM loader and protocol-3 updater stable and maintenance-only, with no further loader feature work planned; retain the current MIDI-time chord grouping and no-reply chord dispatch as the validated playback contract.
- **Why:** The recovery boundaries passed restrained-actuator testing, the instrument-server path updated the complete 14-actuator handpan ring without error, and subsequent playback demonstrated nearly perfect chord synchronization plus substantially cleaner rapid layered melodies.
- **Supersedes:** the updater's development/remaining-full-ring-gate status and closes hardware validation of “Playback chords are MIDI-time groups and do not wait for replies.”
- **Affects:** `README.md`, `docs/firmware-update.md`, `docs/firmware.md`, `docs/host-software.md`, `docs/replication-status.md`, `DebugLog.md`, and Gen1 loader maintenance policy.

## 2026-08-13 — Homing and strike motion have local encoder safety bounds

- **Decision:** Every accepted homing or strike sequence now accumulates absolute encoder travel in the 500 Hz strike task and latches a dedicated motor fault at one revolution (16,384 counts). Homing additionally faults after 5 seconds; strike deliberately has no independent timer because low-current motion may be slow while hazardous high-current runaway consumes the travel allowance quickly. A fault disables PWM and invalidates `homed`; `CLEAR_FAULT` does not restore readiness, so a fresh home is mandatory. A successful home compares its drum position modulo one revolution with the previous known calibration and sets a non-faulting warning at a shift of 1,024 counts (22.5 degrees). `SAVE_SETTINGS` may safely pause an idle home hold to persist that calibration, then resumes the hold.
- **Why:** Bench observation showed that a loose mallet mount can move the ball out of the drum path; without a mechanical impact, the rotor can continue through the strike state at near top speed and throw the mallet or ball. Homing had the same missing termination contract even though its low duty makes it less hazardous.
- **Accepted tradeoffs:** (1) The safety check runs only while a sequence is active and only at 500 Hz, adding no work to the 6 kHz current loop or 20 kHz PWM/ADC path; a fault can therefore occur up to one 2 ms strike tick after the exact threshold. (2) The home-shift warning is advisory and does not block play after homing. (3) Persisting the comparison reference remains an explicit `SAVE_SETTINGS` action, avoiding a flash erase/write and wear on every home.
- **Supersedes:** unbounded `HOME_SEEK_DRUM` / strike recovery motion and fault-clear behavior that could leave a stale homed calibration usable.
- **Affects:** `include/m2003_config.h`, `include/motor.h`, `include/strike.h`, `include/timing.h`, `src/motor.c`, `src/strike.c`, `src/protocol.c`, `src/timing.c`, `scripts/ring_bus.py`, `scripts/ring_tool.py`, `scripts/ring_midi_server.py`, `player/midi_player.html`, `protocol.md`, `midi_server_api.md`, and `docs/firmware.md`.

## 2026-08-13 — Operator features are complete only through the UI/server path

- **Decision:** Firmware behavior is not considered complete until its normal operator workflow is observable and actionable through the MIDI server and browser UI. Ordinary motor and strike tuning supports the same explicit target choices—one selected actuator or every enumerated actuator—and a fleet-applied value remains individually adjustable afterward. The ring command-line tool remains a diagnostic and exceptional-maintenance fallback, not a required step in routine tuning or fault recovery.
- **Why:** The instrument is normally operated through the browser and contains 14 or more actuators. Repeating commands manually is tedious and makes partial application or unnoticed faults more likely.
- **Accepted tradeoffs:** Configuration readback is an on-demand protocol reply rather than an addition to the fast/regular status path. Healthy homed status avoids a redundant full motor query; exact motor fault/state is queried when a slot becomes unhomed. Board-specific electrical CS/LED polarity is visible but excluded from fleet tuning to avoid an accidental ring-wide hardware mismatch.
- **Supersedes:** firmware-only completion judgments and single-actuator-only browser tuning assumptions.
- **Affects:** future review criteria; `src/protocol.c`, `src/persist.c`, `scripts/ring_bus.py`, `scripts/ring_midi_server.py`, `player/midi_player.html`, `player/looper.html`, `protocol.md`, `midi_server_api.md`, `docs/firmware.md`, and `docs/parameters.md`.

## 2026-08-22 — Cross-boot home-shift detection uses the raw absolute angle

- **Decision:** Home-shift detection compares the MT6701 raw 14-bit angle captured at drum contact, while logical continuous positions remain dedicated to motion control. `SAVE_SETTINGS` persists that angle in settings record version 5; v3/v4 records remain readable but establish a warning baseline only after a fresh home and save.
- **Why:** Without an explicit logical zero, the continuous position origin is the arbitrary rotor position at power-up. Persisting that boot-relative coordinate caused false first-home warnings even when the physical drum contact had not moved.
- **Supersedes:** the comparison-coordinate portion of “2026-08-13 — Homing and strike motion have local encoder safety bounds”; explicit save rather than per-home flash writing remains unchanged.
- **Affects:** `src/strike.c`, `include/strike.h`, `src/persist.c`, `protocol.md`, and `docs/parameters.md`.

## 2026-09-13 — MIDI transposition is an explicit, reversible player action

- **Decision:** Imported and library MIDI files retain their original pitches until **Transpose** is clicked. Each application fits the original events to the enumerated instrument's configured pitches, with selectable octave folding, optional pitch substitutions, and track/channel inclusion. **Restore original** reinstates the original events; source bytes and instrument mappings are preserved.
- **Why:** Automatic fitting on open would alter already arranged pieces. Exact pitch sets, rather than scale names or range alone, govern compatibility.
- **Tradeoffs:** Transposed schedules merge simultaneous hits and omit later same-mallet hits under the 50 ms guideline at the chosen speed. Manual fallback routes are bypassed; a changed instrument map requires reapplication. Saving to the library retains the source MIDI; adaptation is not persisted or exported.
- **Affects:** Browser MIDI import, piano roll, scheduling, and `docs/host-software.md`. Server dispatch and firmware protocols are unchanged.

## 2026-09-15 — Transposition ranking excludes mallet timing

- **Decision:** Remove the estimated same-mallet collision count from candidate ranking. Retain the existing ordered pitch-fit, exact-match, movement, and shift preferences; the chosen shift is independent of note timing and playback speed.
- **Why:** Closely spaced notes should not cause a less desirable octave placement when pitch fit is equal.
- **Supersedes:** The collision tie-breaker in the initial MIDI transposition implementation. The separate 50 ms playback restrike handling remains unchanged.
- **Affects:** `player/midi_transpose.js`, the browser Transpose action, and `docs/host-software.md`.

## 2026-09-19 — Multiple serial rings share one MIDI player clock

- **Decision:** Add repeatable `--ring NAME=PORT,COUNT` configurations, fixed global slots, independent serial bridges and per-ring playback workers on one monotonic timeline. Keep wire addresses/protocol and single-ring `-p` behavior unchanged. Global MIDI-time chords retain no-reply dispatch across ring boundaries.
- **Why:** Each ring supports at most 16 actuators; additional adapters expand the instrument without making one ring's reply timeout stall another ring's schedule.
- **Tradeoffs:** Expected counts pin slot offsets; mismatched discovery blocks new playback. Named-ring mappings and browser slot settings are bound to the configured layout. Equal-size physical ring swaps require operator care. Actual cross-ring impact alignment remains a bench gate. Firmware updates stay in single-ring maintenance mode.
- **Affects:** `scripts/ring_fleet.py`, `scripts/ring_midi_server.py`, player/looper ring labels, `docs/host-software.md`, and `midi_server_api.md`.
## 2026-09-19 — Microphone pitch assignment starts with one reviewed mallet

- **Decision:** Detect one selected mallet through browser-local microphone processing, using either one explicit strike at the existing current/trim or a manual tap. A stable estimate becomes a proposed pitch; only Assign persists it through the existing mapping API. Capture ends on completion, cancellation, dialog closure or page hiding. No audio is uploaded or stored.
- **Why:** Isolated notes associate an acoustic measurement with a known actuator while keeping octave mistakes reviewable. Existing motion, homing, transport and firmware behavior are preserved.
- **Tradeoffs:** Detection is bounded to 80–1500 Hz and A4=440; stability does not establish the true fundamental. Full-ring scanning awaits acoustic trials. Calibration has no cross-client reservation. Desktop localhost works immediately; phones require trusted HTTPS. Optional server TLS accepts externally managed certificates, with private reverse proxies also supported; certificate trust and VPN setup remain deployment work.
- **Affects:** Browser player, static asset routes and `docs/host-software.md`.

## 2026-09-20 — Full-ring microphone mapping uses one cancellable capture

- **Decision:** Add an explicit all-mallet scan with one microphone session, frozen pass currents, fresh readiness checks, and a quiet interval referenced to the original noise floor. Preserve completed proposals on stop, allow unresolved-only retries, and save reviewed successes while retaining unresolved mappings.
- **Why:** The user reported reliable mobile recognition on two drums; sequential capture removes repeated operator actions without changing the proven pitch estimator or firmware.
- **Tradeoffs:** No automatic current increases or retry strikes. Acoustic failures may continue after quiet; command/connection failures stop. Hiding the page cancels capture. One operator is required; no cross-client reservation is introduced. Volume normalization remains a proposed follow-up requiring fixed microphone geometry, audio-processing checks, measured trim verification and shared trim persistence.
- **Supersedes:** The full-ring scan deferral in the 2026-09-19 microphone decision.
- **Affects:** `player/pitch_detector.js`, `player/pitch_assignment.js`, `player/midi_player.html`, and the host software guide.

## 2026-09-20 — Pitch scans adapt to background noise and retry silent strikes

- **Decision:** Limit inter-measurement settling to 0.6–1.5 seconds and require a new onset against a rolling pre-strike reference. Accept healthy cached readiness up to two seconds old; retry unavailable status three times on the same mallet. After 1.8 seconds without an audible onset following acknowledgment, retry once at up to 20% / 200 mA extra, capped at 3000 mA, without changing trims. Only exhausted silent attempts advance unresolved; readiness, command or unclear-audio failures stop for intervention.
- **Why:** Mobile trials encountered city noise, long ringdown waits and spurious cached-status skips. The user requested bounded stronger retries and no arbitrary skipping.
- **Supersedes:** Original-noise-floor settling and no automatic retry/current increase in “Full-ring microphone mapping uses one cancellable capture.”
- **Affects:** Browser pitch capture, scan workflow, background probe scheduling and `docs/host-software.md`. Firmware and transport remain unchanged.

## 2026-09-20 — Acoustic retry covers noise-triggered onsets

- **Decision:** Retry the same mallet once after either 1.8 seconds without onset or 3 seconds without a stable pitch, then mark unresolved and continue. Overloaded audio retries at original current; other missed/unclear readings use the bounded increase. Actual readiness/command failures stop with their reason retained in the affected row.
- **Why:** The user reported scans stopping on missed notes with only “Stopped before completion” shown. Background noise can trigger onset without a usable note, so onset alone cannot classify a failed capture as fatal.
- **Supersedes:** The unclear-audio stop rule in “Pitch scans adapt to background noise and retry silent strikes.”
- **Affects:** Browser pitch detector and scan feedback; `docs/host-software.md`.

## 2026-09-20 — Stalled microphone capture has an independent watchdog

- **Decision:** Check wall-clock time before the fresh-audio gate. Try one audio resume after 0.75 seconds without fresh frames, and stop with a specific microphone error after three seconds if it cannot recover. Reject analysis exceptions through the capture promise and require recent running audio before dispatching a strike.
- **Why:** The user reported the scan remaining at the heard-strike message. A frozen or interrupted audio clock bypassed normal timeout checks until the 25-second fallback; a simulated freeze reproduced this path.
- **Affects:** `player/pitch_detector.js` and the host software guide. Healthy-input acoustic retry timing and reviewed mapping saves remain as specified above.

## 2026-09-21 — Optional native M2003 J-Link flash loader

- **Decision:** Add `-NativeFlash` to the existing complete-stack flasher, selecting `M2003FC1AE` for bulk APROM/LDROM downloads with J-Link V9.58+. Retain explicit manifest invalidation and commit-last programming, CONFIG preservation, and independent physical byte verification. Keep the original method available by omitting the switch. Native failures stop without automatic fallback. Add generation-only operation and programming logs/timing.
- **Why:** SEGGER now supports both banks directly. A V12 Compact Base bench test completed a forced full rewrite and verification in 3.375 seconds versus 10.667 seconds for the per-word method, preserving CONFIG and settings.
- **Supersedes:** The per-word-only programming implementation; the complete-stack, boot-configuration, and physical-verification contracts remain in force.
- **Affects:** `scripts/flash-jlink.ps1`, `scripts/make_provision_jlink.py`, build outputs, provisioning tests, and `docs/firmware-update.md`.

## 2026-09-24 — Named instrument pitch maps follow the selected setup

- **Decision:** Store named pitch maps and player settings in `instruments.json`, with one selected profile supplying the existing mapping and pitch-playback APIs. Import an existing `mapping.json` as the Default profile on first save. Browser playback, keyboard routing, looper routing, and pitch discovery consider only currently enumerated actuator slots; saved entries beyond that count stay with their profile but are inactive. Creating a profile copies trims, fallback routes, velocity floor, compensation, and master current.
- **Why:** Switching between drums with different actuator counts left old mallets mapped and could make songs target absent addresses. Named profiles avoid repeated remapping while keeping an instrument's assignments available for later reuse.
- **Supersedes:** A single shared `mapping.json` as the sole persisted pitch map.
- **Affects:** MIDI server mapping API, player and looper routing, microphone assignment, `README.md`, and `midi_server_api.md`.

## 2026-10-02 — Select existing drum profiles independently per ring

- **Decision:** Integrate main's named instrument profiles, microphone/HTTPS flow and dead-strike testing with multi-ring playback. Each ring selects an existing profile; global pitch and trim edits split back into its local profile. Persist ring assignments and shared current/velocity/compensation controls by layout, with stale-selection checks. Keep original single-drum scalar settings and fallback routes intact; combined fallback overrides belong to the selected set of drums.
- **Why:** Two drums on separate serial adapters should reuse their saved calibration without requiring a manually merged profile. Shared controls are the user's chosen trial workflow.
- **Supersedes:** `mapping-rings.json` as the sole multi-ring store; matching legacy mappings remain readable. Fixed slot offsets and independent playback workers remain unchanged.
- **Affects:** `scripts/fleet_instruments.py`, `scripts/ring_fleet.py`, server instrument API, player ring selectors, looper initialization and host/API documentation. Physical cross-adapter timing remains unqualified by software tests.

## 2026-10-02 — Hold the main merge for two-drum hardware testing

- **Decision:** Prepare and commit the integration on `multi-ring`, but defer merging it into `main` until the COM29/COM48 two-drum hardware trial passes.
- **Why:** Builds, simulated serial tests and browser checks do not validate physical routing, homing, playback or impact timing across two adapters.
- **Supersedes:** The plan to merge into `main` immediately after software validation.
- **Affects:** Branch integration and the hardware acceptance checklist in `docs/host-software.md`; no hardware playback has been performed as part of preparation.

## 2026-10-02 — Release the main merge after two-drum playback

- **Decision:** Merge `multi-ring` into `main` following the user's successful two-drum playback report and explicit approval.
- **Why:** The user reports that the COM29/COM48 setup works well and sounds beautiful, with nearly twenty notes opening up more playable music. This supplies the requested physical playback feedback; quantitative impact timing and exhaustive fault testing are not implied.
- **Supersedes:** Hold the main merge for two-drum hardware testing.
- **Affects:** Branch integration and the validation record in `docs/host-software.md`.

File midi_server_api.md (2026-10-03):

# Ring MIDI Server HTTP API

`scripts/ring_midi_server.py` is the host-side bridge between the ring bus
and anything that wants to make the actuators play music or notification
chimes. It owns one or more serial ports, exposes a small REST surface over HTTP,
and serves the browser-based player UI as a side benefit.

This document is the integration reference for that REST surface.

If you're writing a new application that wants to ping the actuators
("play a chime when CI fails", "ring at 9am", "play a melody from a
calendar event"), use the **Friendly API** section. The lower-level
endpoints are documented for completeness and for the browser player.

---

## Running the server

```
python scripts/ring_midi_server.py
python scripts/ring_midi_server.py -p COM7 --http-port 8765
python scripts/ring_midi_server.py --ring pan=COM7,14 --ring drum=COM8,10
```

Common flags:

| Flag | Default | Purpose |
|---|---|---|
| `-p`, `--port` | auto-detect | Serial port for the ring bus |
| `--ring` | (none) | Repeat `NAME=PORT,COUNT` for named rings; each expected count is 1–16; exclusive with `-p` |
| `--baud` | 250000 | Ring baud rate |
| `--host` | `127.0.0.1` | HTTP bind host. Set to `0.0.0.0` to expose on the LAN |
| `--http-port` | 8765 | HTTP bind port |
| `--timeout-ms` | 1000 | Per-frame RX timeout |
| `--library-dir` | (none) | Folder of `.mid`/`.midi` files exposed at `/api/library` |
| `--motif-current-ma`  | 800 | Default master current for pitch-style /api/play requests at velocity 127. 0-3000 mA |
| `--motif-vel-floor` | 0.5 | Default velocity scale floor. See "Velocity curve" below |

Base URL throughout this document is `http://<host>:<http-port>`.
All endpoints accept any `Origin` (CORS is open by default), so calling
from a browser on another port is fine.

> **Windows gotcha:** the server binds IPv4 only by default. Python's
> `urllib` (and a few other clients) resolve `localhost` to `::1` first
> and eat a ~2 s IPv6 connect timeout before falling back to IPv4. Use
> `http://127.0.0.1:8765` from Python clients on Windows to skip that
> entirely. curl and browsers do not hit this.

---

## Quickstart

Three calls to play a chime:

```bash
# 1. Discover what pitches are currently mapped to actuators.
curl http://localhost:8765/api/pitches

# 2. Build a motif (chord on the first three pitches, t_ms is absolute).
curl -X POST http://localhost:8765/api/play \
  -H 'Content-Type: application/json' \
  -d '{
    "name": "ci-passed",
    "master_current_ma": 1000,
    "events": [
      {"t_ms": 0,   "pitch": 60, "velocity": 100},
      {"t_ms": 0,   "pitch": 64, "velocity": 100},
      {"t_ms": 0,   "pitch": 67, "velocity": 100},
      {"t_ms": 300, "pitch": 72, "velocity": 110}
    ]
  }'

# 3. (Only if you need to interrupt before duration_ms is up.)
curl -X POST http://localhost:8765/api/cancel
```

The motif POST returns immediately with a motif id, the scheduled
duration, and the list of any events that had to be skipped (e.g.
because the pitch isn't mapped). Playback is fire-and-forget; you do
not need to keep the connection open.

---

## Concepts

### Mapping: slot ↔ pitch

In named-ring mode all API `address`, `addresses`, `slot`, and `muted` fields
refer to **global slots**, formed by concatenating configured rings in CLI
order. For `pan=COM7,14` followed by `drum=COM8,10`, global slot 14 routes to
local address 0 on COM8. Local wire addresses remain 0–15; no firmware change
is required. Both canonical and pitch-style `/api/play` span rings.

`GET /api/status` adds `rings: [{name, port, offset, count, expected_count,
ready}]`; each slot adds `ring`, `port`, `local_address`, and global `address`.
The top-level `count` stays at the configured total after failed discovery;
unavailable slots have `homed: false` and `status_error`. New playback requires
all rings enumerated at their expected counts. `/api/enumerate` stops playback
before discovery and reports errors without changing global slot positions.

`GET /api/mapping` additionally returns `context` (an opaque layout identifier
in named-ring mode, null otherwise). Named-ring selections and shared controls
use `instruments-rings-<context>.json`; selected profiles remain in
`instruments.json`. Mapping saves require exactly the configured number of
entries and split edits back into each selected drum's local mapping. Unselected
rings are null unless migrating a matching legacy `mapping-rings.json`.
Browser slot settings are namespaced by layout and selected instruments.
Reload clients when changing the server layout or selections.
Duplicate pitches resolve to the first slot; canonical address events can
target duplicate-pitch actuators separately.

Independent playback workers share a monotonic start time, cancellation, live
scaling, mute set and aggregate playback statistics. Each adapter retains its
own serial lock and latency estimates. No-reply chords are identified from
the complete song, even when only one note of a chord falls on a ring. Other
rings continue if one ring times out; cancellation joins every worker before
sending cancels concurrently across rings. This does not guarantee a specific
cross-adapter physical timing tolerance.

`GET /api/firmware` adds `update_supported: false` in named-ring mode;
`POST /api/firmware/update` returns 409 there. Use the existing `-p PORT`
maintenance workflow for one ring at a time. See
[`docs/host-software.md`](docs/host-software.md#multiple-rings-on-one-server)
for setup and validation limits.

In single-ring mode, the physical ring has N actuators ("slots", addressed 0..N-1). A saved
instrument mapping has one entry per configured mallet, where each entry is either
a MIDI pitch number (0-127) or `null` (slot disabled / not used in this
song). It's persisted to `instruments.json` at the project root, so it
survives server restarts and is shared across every browser that
connects to the bridge. Only addresses 0..N-1 are playable when the connected
ring has fewer actuators than the saved instrument.

Integrations talk in **MIDI pitch numbers**, not slot indexes. The
bridge looks each pitch up in the mapping and routes the strike to the
matching slot. Unmapped pitches are silently skipped (and reported back
in the response so the caller can tell).

You can fetch the human-friendly form via `GET /api/pitches`, which
already filters out null slots and sorts by pitch ascending. Use that
for any "what's available" discovery.

### Selecting existing instruments per ring

In named-ring mode `GET /api/instruments` returns the existing single-drum
`profiles` list plus `rings: [{name, port, count, offset, profile_id}]`.
`active` is an opaque token identifying the complete selection, and `settings`
contains combined trims/fallbacks plus the shared player controls. Load a drum
with `POST /api/instruments`:

```json
{"action":"select_ring","ring":"jameson","id":"<saved-profile-id>","expected_id":"<active-token>"}
```

The response includes the updated `active`, `rings`, `settings` and global
`mapping`. Selection is rejected during scheduled playback. Give each ring a
different saved profile. Use the returned active token for `profile_id` on
mapping saves and `id` on `update_settings`; stale tokens are rejected.
The first selection seeds shared current/velocity/compensation from that drum;
later selections preserve them. Trim and pitch edits update the selected
profiles, while shared controls do not alter their standalone defaults.
Fallback edits are stored for this selection; original profile routes remain
unchanged. Profile create/rename/delete actions remain available in single-ring
mode. Single-ring `/api/instruments` behavior is unchanged.

### Velocity curve

Every motif event carries a MIDI velocity (0-127). The bridge maps it
to a strike current in mA using the same curve as the browser player:

```
scale      = vel_floor + (1 - vel_floor) * (velocity / 127)
current_ma = master_current_ma * scale          # clamped to [0, 3000]
```

- `master_current_ma` is the max current — what you'd get at velocity 127.
- `vel_floor` is the floor of the scale. `vel_floor = 1.0` ignores
  velocity entirely (every note plays at master). `vel_floor = 0.5`
  (default) makes velocity 1 play at half master. `vel_floor = 0.0`
  makes soft notes barely strike.

Server-wide defaults come from `--motif-current-ma` and
`--motif-vel-floor`. Any individual `POST /api/play` can override
them with `master_current_ma` and `vel_floor` fields, applied only to
that motif. Out-of-range values are clamped; the response echoes back
the values actually used.

### Latency compensation

Sending a strike command and waiting for the mallet to physically hit
the tine isn't instantaneous — it's tens of milliseconds, varies with
strike current, and varies slot-to-slot. The bridge keeps a per-slot
per-current-bucket EMA of `trigger_to_impact_ms` (the
`LatencyTracker`), fed by every strike that flows through it (browser
or motif). Motif playback uses that table to fire each strike command
*early* enough that the mallet impact lands on the intended beat. You
don't need to do anything to opt in — just send `t_ms` values that
reflect when you want the *impact* to happen, and the bridge handles
the offset.

Beats stay flush even for chords (multiple events at exactly the same `t_ms`).
Only events sharing that MIDI impact time are eligible to share a command
train; a later note is never pulled into a chord merely because latency
compensation gives it a similar transmission deadline. Chord members whose
compensated trigger deadlines fall within 1 ms are emitted farthest-address
first without waiting between commands. Playback chord commands request no
reply, so a missing ACK cannot stall the real-time scheduler. Isolated notes
retain `ACK_TIMED`, and explicit timing polls remain available for learning and
diagnostics.
The EMA needs a handful of strikes to converge on a slot if the bridge
has just started; the first few strikes use a 50 ms default.

### Preemption

There is exactly one motif slot. Posting a new motif preempts whatever
was playing — the previous worker's stop event is set, the worker is
joined (2 s timeout), and the new motif starts only after that worker exits.
If it does not exit, the server preserves its identity and returns HTTP 409
instead of allowing two playback workers to overlap. `POST /api/cancel`
also stops any running motif.

---

## Friendly API

The integration surface. Use these endpoints unless you specifically
need direct ring access.

### `GET /api/status`

Latest observed ring state. Refreshes while idle; uses cached readings during
server playback or bus contention.

**Response (200):**
```json
{
  "count": 5,
  "homed": [true, true, false, true, true],
  "status_deferred": false,
  "slots": [
    {
      "homed": true,
      "status_cached": false,
      "status_age_ms": 12,
      "home_shift_warning": false,
      "fault": 0,
      "fault_name": "NONE",
      "home_offset": 120,
      "coast_distance": 80,
      "homing_duty": 600,
      "last_timing": {
        "address": 0, "sequence": 41, "flags": 1,
        "trigger_to_coast_ms": 22.5, "trigger_to_impact_ms": 38.1,
        "trigger_to_rebound_ms": 52.0,
        "estimated_strike_velocity_dps": 1450,
        "rebound_timeout": false
      }
    }
  ]
}
```

`last_timing` is only present if at least one strike has completed on that
slot since the bridge started. To preserve ring bandwidth, healthy homed slots
do not receive a second full motor query: their fault is known to be `NONE`
because firmware invalidates homing on every fault. Unhomed slots are queried
for exact `fault`, `fault_name`, `motor_state`, and `motor_state_name` values.

Status polling releases the bus after every transaction, including before an
unhomed slot's optional motor-status query. Waiting commands take priority.
During server playback, no status queries are sent. Overlapping status/probe
requests return cached data instead of queuing another sweep.

- `status_deferred`: at least one slot could not be fully refreshed for this
  request (busy bus, playback, another sweep, or a failed strike-status query).
- Per-slot `status_cached`: this request did not fully refresh that slot.
- Per-slot `status_age_ms`: elapsed time since its last successful strike-status
  read, or `null` if none exists. Supplemental motor details may be unavailable.
- Per-slot `status_error`: last query failure, or an explanation that no reading
  exists yet. A failure retains the previous reading and its original age.

Treat `homed` and fault values as last-known observations, not live guarantees.
For homing/recovery completion, require a fresh result without `status_error`.
Re-enumeration and firmware updates discard cached address identities. Cached
responses do not trigger background retries; request status again while idle
for a fresh sweep. The browser marks cached/unavailable state explicitly.

### `GET /api/pitches`

Currently mapped pitches with note names. The recommended discovery
endpoint for integrations.

**Response (200):**
```json
{
  "pitches": [
    {"pitch": 60, "name": "C4",  "slot": 0, "homed": true},
    {"pitch": 64, "name": "E4",  "slot": 1, "homed": true},
    {"pitch": 67, "name": "G4",  "slot": 2, "homed": true},
    {"pitch": 72, "name": "C5",  "slot": 3, "homed": true},
    {"pitch": 76, "name": "E5",  "slot": 4, "homed": true}
  ]
}
```

Sorted ascending by pitch. `homed: false` means the actuator hasn't
self-homed yet — strikes will likely fail or be inaccurate. Empty list
means no mapped pitch belongs to a currently enumerated actuator.

### `GET /api/mapping`

The raw slot-indexed mapping. Lower-level than `/api/pitches`; integrations
usually want `/api/pitches` instead.

**Response (200):**
```json
{ "mapping": [60, 64, 67, 72, 76] }
```

If no mapping has been saved, `"mapping": null`.

The selected instrument's full saved mapping is returned. Entries beyond the
currently enumerated actuator count are saved for that instrument but are not
reported by `/api/pitches` or used for playback.

### `GET /api/instruments` and `POST /api/instruments`

Named instrument profiles live in `instruments.json`. Each stores its pitch map,
per-mallet trims, fallback routes, velocity floor, compensation settings, and
master strike current. Existing `mapping.json`
is imported as the Default profile when profiles are first saved. The active
profile supplies `/api/mapping` and pitch-based playback.

`GET` returns `{"active":"default","profiles":[{"id":"default","name":"Default","count":10}]}`.
`POST` accepts `{"action":"create","name":"Handpan","mapping":[...],"settings":{...}}` to
save the current setup as a new active profile. Use `{"action":"select","id":"..."}`
to load one, `{"action":"rename","id":"...","name":"..."}` to rename it,
or `{"action":"delete","id":"..."}` to remove it. Use
`{"action":"update_settings","id":"...","settings":{"vel_floor":0.5}}`
to update player settings. At least one profile is retained. Responses include
the active profile's `mapping` and `settings`.

### `POST /api/play`

Schedule and play a motif. Fire-and-forget. Preempts any in-flight motif.

**Request body:**
```json
{
  "name": "ci-passed",
  "master_current_ma": 1000,
  "vel_floor": 0.5,
  "events": [
    {"t_ms": 0,   "pitch": 60, "velocity": 100},
    {"t_ms": 250, "pitch": 64, "velocity": 100},
    {"t_ms": 500, "pitch": 67, "velocity": 100}
  ]
}
```

| Field | Type | Required | Notes |
|---|---|---|---|
| `events` | array | yes | One element per note. Order doesn't matter; the server sorts by `t_ms` |
| `events[].t_ms` | int >= 0  | yes | Absolute time from motif start. Multiple events at the same `t_ms` form a chord |
| `events[].pitch` | int 0-127 | yes | MIDI pitch. Unmapped pitches are skipped (reported in response) |
| `events[].velocity` | int 0-127 | no | Default 100. Maps to current_ma via the velocity curve |
| `name` | string | no | Free-form label. Echoed in the response and in `Player.status()` |
| `master_current_ma` | number | no | Per-motif master current. Defaults to `--motif-current-ma`. Clamped to [0, 3000] |
| `vel_floor` | number | no | Per-motif velocity floor. Defaults to `--motif-vel-floor`. Clamped to [0.0, 1.0] |

**Response (200):**
```json
{
  "ok": true,
  "id": "a1b2c3d4",
  "name": "ci-passed",
  "duration_ms": 500,
  "scheduled": 3,
  "skipped": [
    {"t_ms": 750, "pitch": 96, "reason": "unmapped"}
  ],
  "master_current_ma": 1000,
  "vel_floor": 0.5
}
```

- `id` is a short hex token; useful for logging which motif is playing.
- `duration_ms` is the `t_ms` of the last scheduled event — i.e. when
  the final mallet impact is expected. The server does *not* wait that
  long; the call returns as soon as the worker thread is started.
- `scheduled` is the count of events that will actually fire.
- `skipped` lists events that won't fire and why. Today the only reason
  is `"unmapped"`. Skipped events still parse — they fail open so a
  partially-mapped ring can still play what it can.

**Error responses (400):**

```json
{ "error": "expected {'events': [...]}" }
{ "error": "'name' must be a string" }
{ "error": "'master_current_ma' must be a number" }
{ "error": "'vel_floor' must be a number" }
{ "error": "motif event t_ms must be >= 0, got -5" }
{ "error": "motif event pitch out of range: 200" }
{ "error": "bad motif event {...}: ..." }
```

### `GET /api/play`

Snapshot of the currently running playback. Useful for polling — the
`POST /api/play` call is fire-and-forget, so this is how callers learn
when playback is about to finish without having to track `duration_ms`
themselves.

The shape is the same whether playback was started via the pitch-style
or canonical-form `POST /api/play`. Anything stashed in metadata at
play-time (`name`, `master_current_ma`, `vel_floor` from pitch-style;
`schedule_master_ma` from canonical) is spread into the response.

**Response (200), playing pitch-style:**
```json
{
  "playing": true,
  "id": "a1b2c3d4",
  "scheduled": 3,
  "cursor": 1,
  "duration_ms": 500,
  "elapsed_ms": 213,
  "remaining_ms": 287,
  "master_scale": 1.0,
  "muted": [],
  "dispatch_stats": {
    "attempted": 2, "accepted": 0, "unacknowledged": 2, "rejected": 0,
    "transport_failed": 0, "muted": 0, "bursts": 1, "reasons": {}
  },
  "name": "ci-passed",
  "master_current_ma": 1000,
  "vel_floor": 0.5
}
```

**Response (200), idle:**
```json
{
  "playing": false,
  "id": null,
  "name": null,
  "scheduled": 0,
  "cursor": 0,
  "duration_ms": null,
  "elapsed_ms": null,
  "remaining_ms": null,
  "master_scale": 1.0,
  "muted": [],
  "dispatch_stats": {
    "attempted": 3, "accepted": 1, "unacknowledged": 1, "rejected": 1,
    "transport_failed": 0, "muted": 0, "bursts": 1,
    "reasons": {"REJECT_NOT_READY": 1}
  },
  "master_current_ma": null,
  "vel_floor": null
}
```

- `cursor` is the index of the next event the worker will dispatch.
  `cursor == scheduled` once playback finishes.
- `master_scale` and `muted` reflect any live tweaks from
  `/api/play/update`. They reset on each `/api/play`.
- `dispatch_stats` is retained after the worker finishes so the final idle
  poll can report accepted firmware ACKs, intentionally unacknowledged chord
  transmissions, device rejections, missing/failed transport replies, muted
  events, and chord-burst count. `unacknowledged` means the complete command
  was written with reply mode `NONE`; it is not an inferred acceptance.
- `elapsed_ms` and `remaining_ms` are computed from the server's
  monotonic clock at the time of the request. They're clamped so that
  `elapsed_ms + remaining_ms == duration_ms` once the schedule is
  complete; the worker thread may keep `playing: true` for a brief
  moment after `remaining_ms` reaches 0 while it tears down. Treat
  `playing: false` as the authoritative "done" signal.

### `POST /api/play` (canonical form)

The browser player uses a second event shape that bypasses pitch resolution
and the velocity curve — the events are already tied to ring addresses and
specific currents:

```json
{
  "master_ma": 800,
  "events": [
    {"t_ms": 0,    "address": 0, "nominal_current_ma": 600},
    {"t_ms": 250,  "address": 2, "nominal_current_ma": 750}
  ]
}
```

`master_ma` is informational — it's the master the caller used when
computing each `nominal_current_ma`. `POST /api/play/update` uses it as
the denominator when computing the live scale ratio. The server detects
this form vs the pitch-style form by looking at the first event's keys.

### `POST /api/play/stop`

Stop the in-flight playback worker. Does NOT disable motors (use
`/api/stop` for that, or `/api/cancel` for a full panic stop).

**Request body:** none.

**Response (200):** `{"ok": true}`

### `POST /api/play/update`

Apply live tweaks to in-flight playback. Both fields are optional and
independent. Takes effect on the next strike.

**Request body:**
```json
{
  "master_scale": 1.25,
  "muted": [3, 7]
}
```

Or send a new master in mA along with the schedule's original master and
let the server divide:

```json
{
  "master_ma": 1000,
  "schedule_master_ma": 800,
  "muted": []
}
```

| Field | Type | Notes |
|---|---|---|
| `master_scale` | number | Direct multiplier on every event's nominal current. Wins if both forms set |
| `master_ma` | number | New master mA. Combined with `schedule_master_ma` → ratio |
| `schedule_master_ma`  | number | Original master used when computing the schedule's nominal currents |
| `muted` | int[] | Addresses to skip until the next update. `[]` clears the mute set |

**Response (200):** echoes the new state. Example:
```json
{"ok": true, "master_scale": 1.25, "muted": [3, 7]}
```

### `POST /api/cancel`

Stop the running playback (if any) and cancel all in-flight strikes
across the ring. Panic stop.

**Request body:** none.

**Response (200):**
```json
{
  "ok": true,
  "failed": [],
  "results": [
    {"address": 0, "accepted": true, "result": 0, "result_name": "OK", "detail": 12}
  ]
}
```

If any actuator rejects the command or fails to reply, the server still
attempts every address and returns `502` with `ok: false`, the failed address
list, and every per-address result. The failed transaction is also counted in
bus-health telemetry.

---

## Building good chimes

A few patterns that work well in practice:

- **Acknowledgement / success** — a short ascending arpeggio over
  ~300-500 ms. Three notes at velocity 90-110.
- **Failure / error** — a descending two-note interval (e.g.
  perfect fourth or tritone) at higher velocity, ~250 ms gap.
- **Attention / notification** — a single high-pitched strike at
  high velocity, optionally followed by a quieter echo at half master.
- **Doorbell** — two pitches a perfect fourth apart with ~400 ms gap,
  e.g. G4 then D4.
- **Top-of-hour** — single low pitch repeated N times, ~500 ms apart,
  N = number of the hour (12-hour clock).

Keep total duration short (under ~2 s for chimes) and leave at least
~150 ms between strikes on the *same* slot — the firmware needs time to
home the mallet back to its rest position before another strike will
register cleanly. Multiple events at the same `t_ms` on *different*
slots are fine and form a chord.

If you're playing actual music, run it through the browser player at
`http://localhost:8765/` first — it shares the same mapping and the
same latency table, so it's the fastest way to validate that a piece
sounds right on the current ring layout.

---

## Firmware maintenance

The server can build the firmware from its own repository checkout and update
the complete protocol-3 actuator ring without closing/reopening the serial
port. These endpoints are asynchronous; poll `GET /api/firmware` for progress.
They are intended for the browser Firmware panel, but use ordinary JSON.

The server must have GNU Make, `arm-none-eabi-gcc`, `arm-none-eabi-objcopy`, and
`arm-none-eabi-size` in its `PATH`. The Makefile supports Windows and POSIX
hosts, including Raspbian. The server always runs the fixed command `make` with
the repository root as its working directory; the API cannot supply shell text,
build arguments, paths, or Git operations. Failed build output is retained for
the browser and also written to the server shell.

### `GET /api/firmware`

Returns the current build/update state. `phase` is one of `idle`, `building`,
`ready`, `stopping_playback`, the structured loader phases (`enumerating`,
`entering_loader`, `loader_ready`, `broadcast_begin`, `writing`, `verifying`,
`repairing`, `committing`, `restarting`), `complete`, or `failed`.

```json
{
  "busy": false,
  "operation": null,
  "phase": "ready",
  "message": "Firmware ready: 27480 bytes, CRC32 349FA335",
  "progress": null,
  "artifact": {
    "path": "build/m2003-motor.bin",
    "image_size": 27480,
    "image_crc32": 882877237,
    "image_crc32_hex": "349FA335",
    "image_version": 20260802,
    "commit": "0123456789ab",
    "dirty": false,
    "built_at": "2026-08-02T20:15:00Z"
  },
  "result": null,
  "error": null,
  "log": "...make output..."
}
```

The prepared bytes are frozen in server memory. The subsequent update uses
those exact bytes even if the checkout or build directory changes afterward.
`dirty: true` means the build included uncommitted/untracked checkout changes.

### `POST /api/firmware/build`

```json
{ "image_version": 20260802 }
```

Starts a server-side `make` and returns 202 with the initial state. The version
must fit uint32 and is a manifest label, not an anti-rollback counter. A new
build discards the previous frozen artifact before starting; a failed build
therefore cannot accidentally leave the old image enabled for update. Returns
409 if a firmware build/update is already active.

Building does not reserve the ring; music may continue while the compiler runs.
Only `POST /api/firmware/update` enters maintenance mode.

### `POST /api/firmware/update`

```json
{
  "confirm": true,
  "expected_crc32": 882877237
}
```

Starts the protocol-3 full-ring update and returns 202. The explicit boolean
confirmation and numeric CRC are required; a stale/mismatched CRC returns 409.
The server stops playback, rejects new ring work, and holds the bridge lock for
the complete operation. The shared data phase is followed by per-device CRC
verification, addressed repair where needed, per-device commit, APROM restart,
re-enumeration, and status response.

During the update, ring-touching endpoints return 409 `firmware update in
progress`. Mapping, MIDI-library, cached playback state, cached bus-health, and
firmware-state requests remain available. On success every actuator must be
re-homed. On failure, one or more actuators may remain safely in LDROM; retry the
same frozen artifact after correcting the cause.

There is no authentication layer and the API allows cross-origin callers, like
the rest of this work-network service. Anyone who can reach it can start a
firmware build or update.

---

## Lower-level endpoints

These exist primarily for the browser player and bench tooling. Most
integrations won't need them, but they're available.

### `POST /api/enumerate`

Re-walk the ring and rebuild the slot list. Use after physically adding
or removing devices.

**Response (200):** `{"count": N}`

### `POST /api/home`

Send a homing command to each addressed slot. The command ACK reports whether
homing actually started; motion remains asynchronous, so poll `/api/status`
to see the `homed` flag flip.

**Request body:** `{"addresses": [0, 1, 2]?}` (omit to home all)

**Response (200):** `{"ok": true, "addresses": [0, 1, 2], "results": [<ack>, ...]}`

`ok` is false if any address rejects the command or has a transport error.

### `POST /api/recover`

Clear a reported fault and immediately start a mandatory fresh home on each
selected actuator. This is the normal UI fault-recovery operation.

**Request body:** `{"addresses": [2, 5]}` (non-empty list required)

**Response (200):** `{"ok": true, "failed": [], "results": [<clear + home result>, ...]}`

The home motion is asynchronous; poll `/api/status` until the selected slots
report `homed: true`.

### `POST /api/strike`

Single direct strike, bypassing the motif scheduler. No latency
compensation. Returns the firmware ACK and the timing block for the
*previous* completed strike on that slot.

**Request body:** `{"address": 0, "current_ma": 1200}`

Optional `"strike_type": "dead"` tests a dead strike with the drive's current
dead-strike tuning and default contact dwell. Omit it (or use `"normal"`) for
a normal strike. Dead strikes do not train normal-strike latency compensation.

**Response (200):**
```json
{
  "address": 0,
  "accepted": true,
  "result": 0,
  "result_name": "OK",
  "detail": 0,
  "metrics": { "address": 0, "sequence": 42, "trigger_to_impact_ms": 38.1, ... }
}
```

### `POST /api/strikes`

Batch direct strikes. Same semantics as `/api/strike`, executed
sequentially under the ring lock.

**Request body:**
```json
{
  "strikes": [
    {"address": 0, "current_ma": 1000},
    {"address": 2, "current_ma": 1200}
  ]
}
```

**Response (200):** `{"results": [<ack>, <ack>]}`

### `POST /api/strike-param`

Set a strike-related parameter on a single slot. Used by the tuning UI.

**Request body:**
```json
{ "address": 0, "param": "home_offset", "value": 120 }
```

Valid `param` values: `"home_offset"`, `"coast_distance"`, `"homing_duty"`,
`"mute_brake_ms"`, `"mute_press_ma"`, and `"mute_engage_offset"`.

### `GET /api/config?address=N`

Read the selected actuator's complete tuning snapshot: velocity PID and
feedforward, position PID, current PI, torque limit, all six strike parameters,
and persistence/electrical-calibration flags. This is an on-demand operation,
not part of regular status polling.

### `POST /api/config`

Apply one ordinary tuning group to any non-empty address list. A single address
and the complete fleet use exactly the same operation, so a fleet value can
always be overridden later on one actuator.

```json
{"addresses":[0,1,2], "group":"velocity_pid", "kp":1536, "ki":10, "kd":20}
```

Groups are `velocity_pid` (`kp`, `ki`, `kd`), `velocity_ff` (`value`),
`position_pid` (`kp`, `ki`, `kd`), `current_pi` (`kp`, `ki`), `torque_limit`
(`value` in mA), and `strike_param` (`param`, `value`). Board-specific CS/LED
polarity is intentionally excluded from fleet tuning.

### `POST /api/stop`

Send coordinated `STOP` to each addressed slot — disables PWM, aborts any
active strike/homing state, and clears the runtime `homed` flag. Re-home the
slot before striking again. Different from `/api/cancel`, which asks an active
strike sequence to return through its normal cancel path.

**Request body:** `{"addresses": [0, 1]?}` (omit for all)

**Response (200):** `{"results": [<ack>, <ack>]}`

### `POST /api/save-settings`

Persist the complete current tuning/calibration snapshot on each addressed
slot to that device's NVM. Firmware safely pauses an idle home hold around the
flash operation; an active strike remains NOT_READY.

**Request body:** `{"addresses": [0, 1]?}` (omit for all)

**Response (200):** `{"results": [<ack>, <ack>]}`

### `GET /api/strike-timing`

Cached per-slot strike-timing snapshots, harvested from every strike
that flows through the bridge.

**Response (200):**
```json
{
  "slots": [
    { "address": 0, "sequence": 41, "trigger_to_impact_ms": 38.1, ... },
    null,
    { "address": 2, ... }
  ]
}
```

Slots with no completed strikes yet are `null`.

### `GET /api/strike-timing?address=N`

Synchronous fresh poll of one slot's strike-timing block. Returns the
same shape as one entry of `/api/strike-timing.slots`, or
`{"address": N, "sequence": 0, "flags": 0}` if the slot hasn't
completed any strike yet.
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

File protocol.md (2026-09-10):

# Ring Bus Protocol v2

Binary framing protocol for the BL4818 motor driver ring bus.
Up to 16 devices, single master, 250 kbaud UART.

## Packet Structure

```
 0       1       2       3        3+LEN   4+LEN
+-------+-------+-------+--------+-------+-------+
| 0xA5  | 0x5A  |  LEN  | payload|CRC_HI |CRC_LO |
+-------+-------+-------+--------+-------+-------+
 preamble        ^                 ^
                 |                 |
                 +-- LEN bytes ----+
```
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

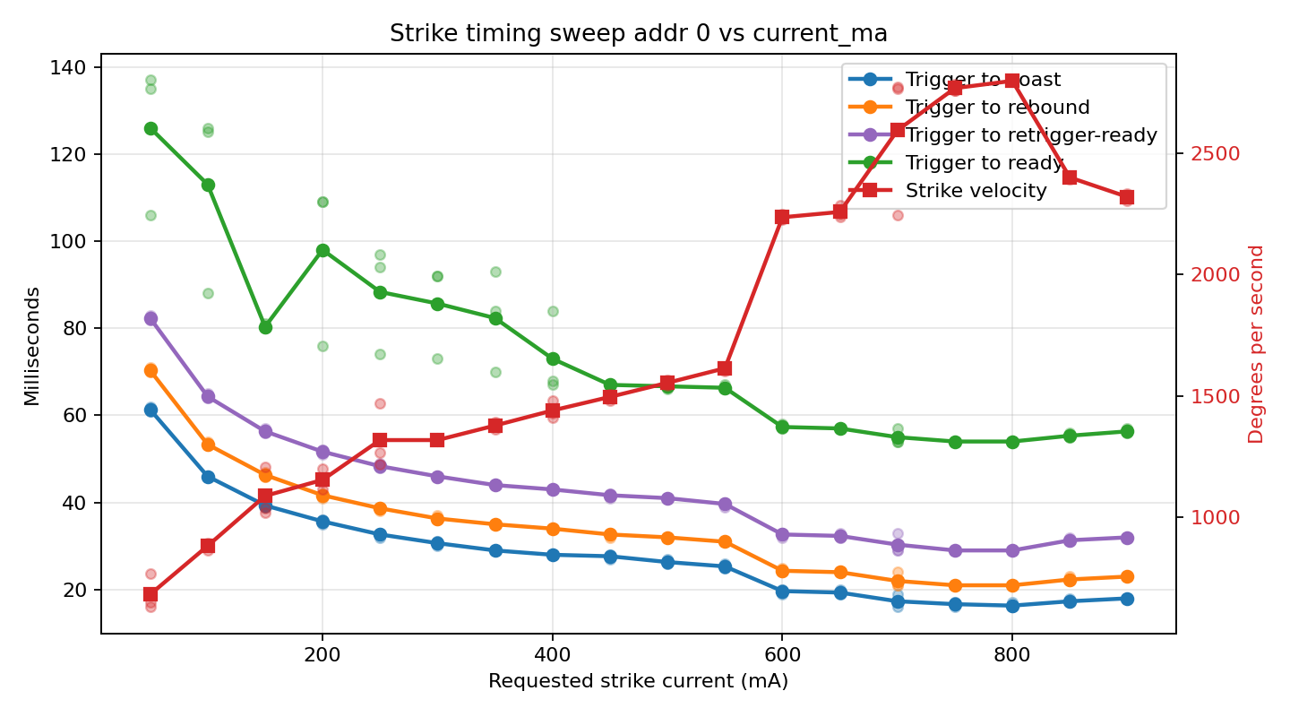
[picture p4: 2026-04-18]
strike_timing.png

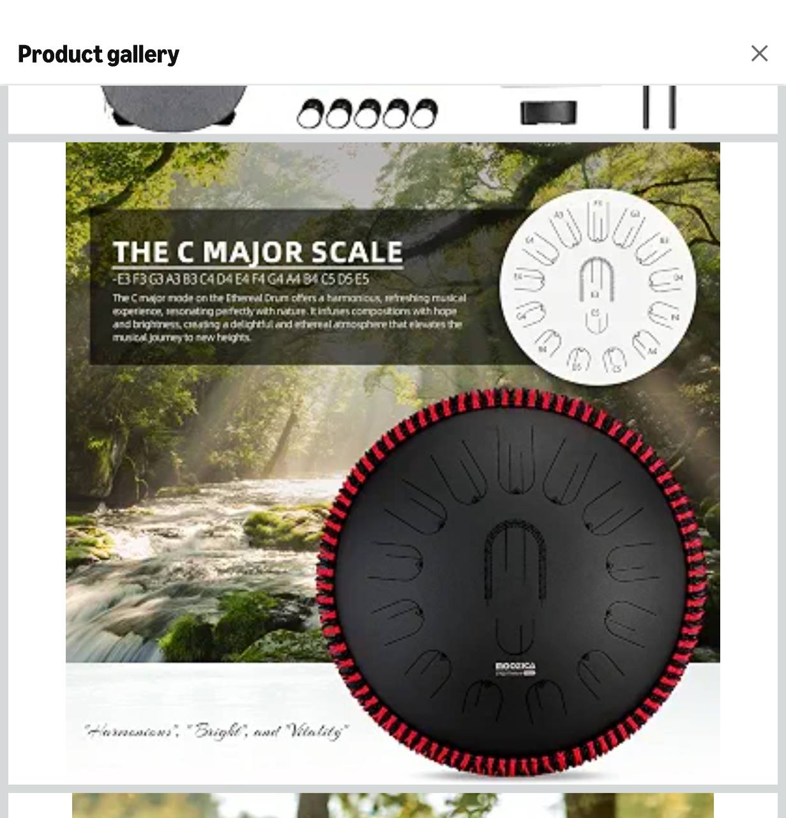
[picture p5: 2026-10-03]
.codex-remote-attachments/01a0a84b-cbda-7ac2-a19b-60dd9f76d342/510a964a-fb66-4376-a0db-de65eab9f907/1-Photo-1.jpg

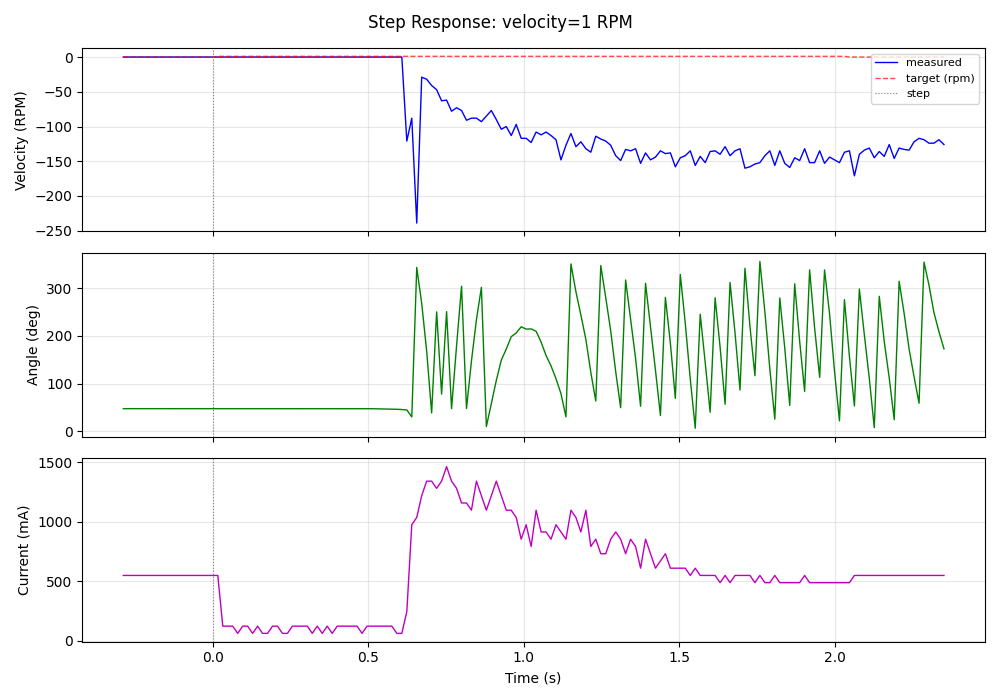
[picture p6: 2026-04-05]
scripts/Figure_1.png

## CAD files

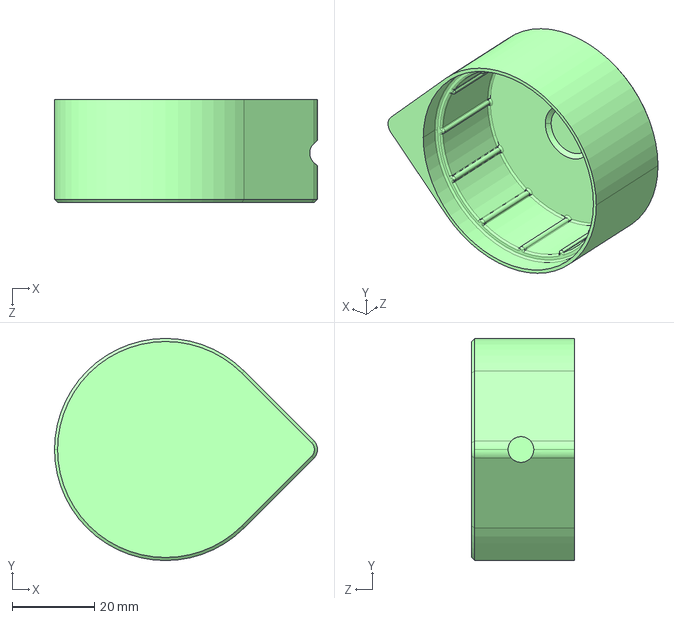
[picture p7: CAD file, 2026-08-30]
mechanical/print-files/mallet_holder.STEP
63.9 x 54.0 x 25.0 mm

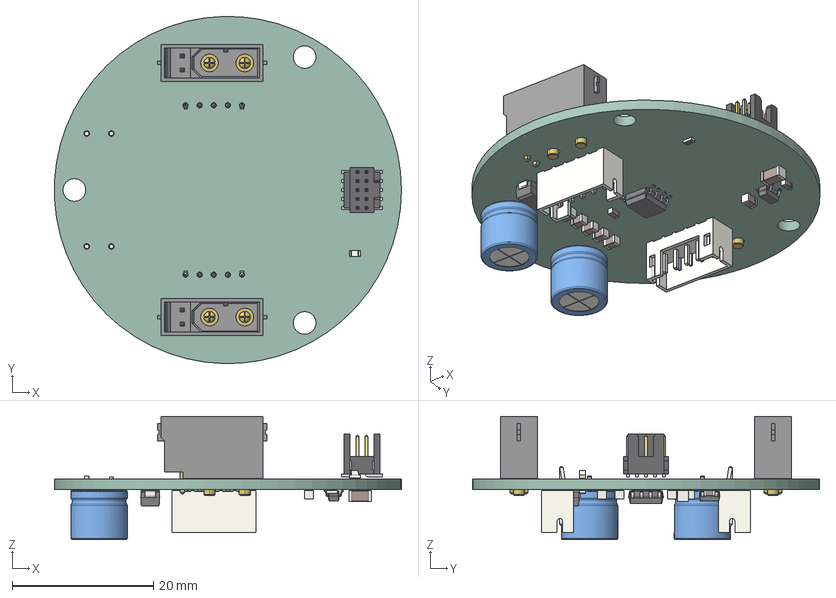
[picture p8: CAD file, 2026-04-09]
pcb/interface/interface.step
49.2 x 49.2 x 17.5 mm
FTSH-105-01-L-DV-K-P_body
FTSH-105-01-L-DV-K-P_pins1
FTSH-105-01-L-DV-K-P_pins2
XT30PB x 2
LED_0603_1608Metric
R_0603_1608Metric
C_0805_2012Metric x 7
SOT-23-5
D_SMA
C_Radial_D8.0mm_H7.0mm_P3.50mm x 2
SO-8_3.9x4.9mm_P1.27mm
C_0603_1608Metric x 2
JST_PH_B5B-PH-K_1x05_P2.00mm_Vertical x 2
C_1206_3216Metric
interface_PCB

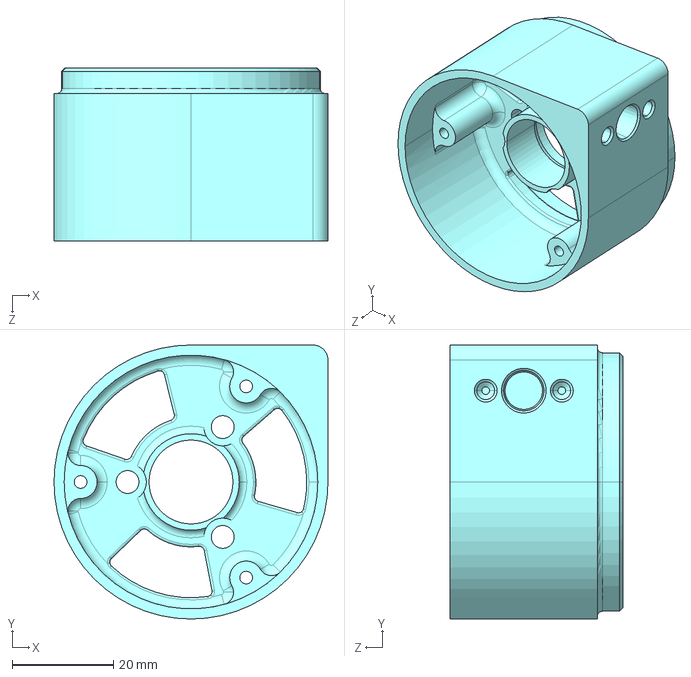
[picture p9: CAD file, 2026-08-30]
mechanical/print-files/base.STEP
54.0 x 54.0 x 34.0 mm

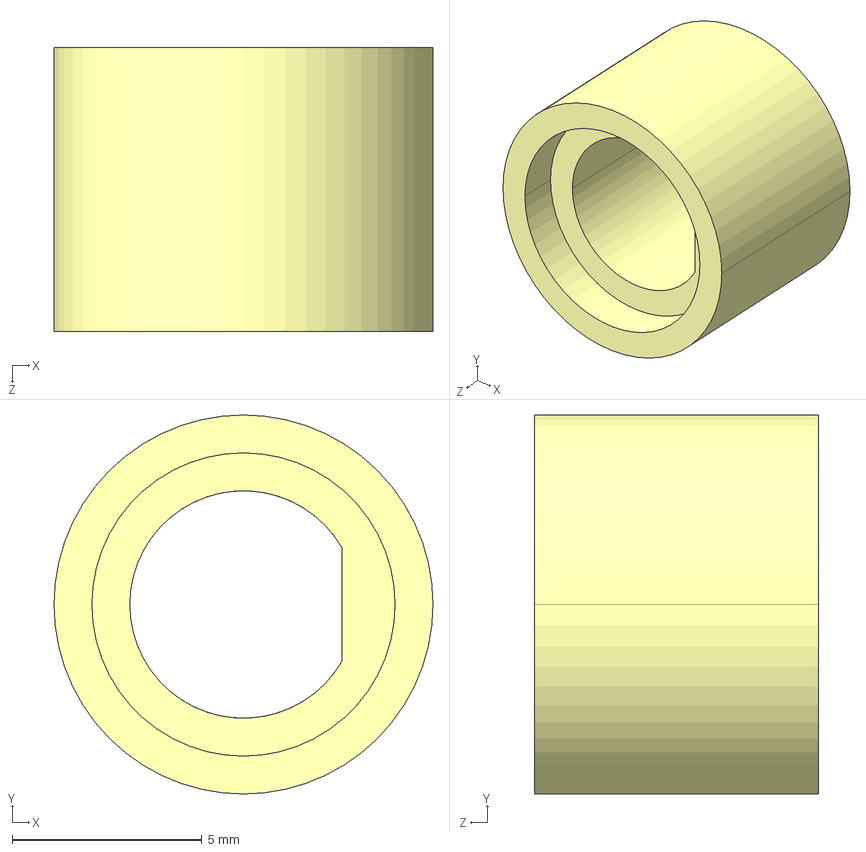
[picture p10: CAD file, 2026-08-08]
mechanical/print-files/mag_collar.STEP
10.0 x 10.0 x 7.50 mm

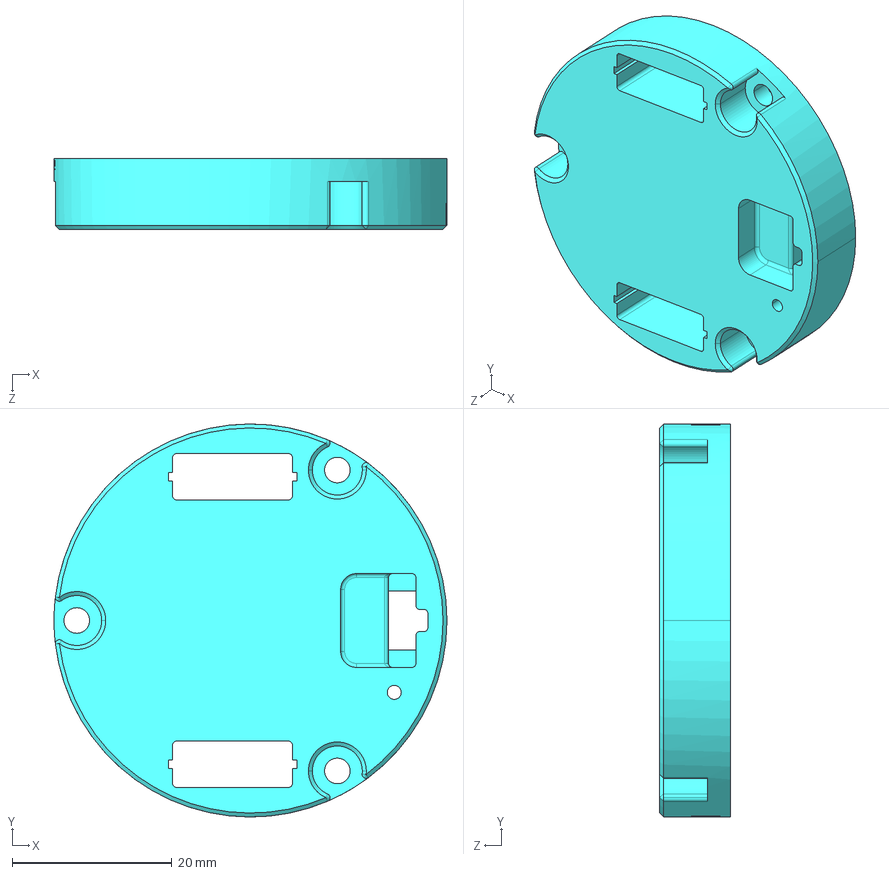
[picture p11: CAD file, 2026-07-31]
mechanical/print-files/encodercover.STEP
49.2 x 49.2 x 8.89 mm

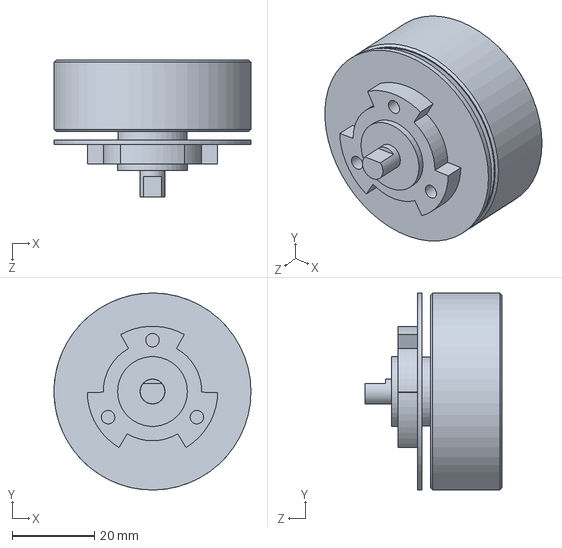
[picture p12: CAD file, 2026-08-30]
mechanical/source/BL4825.SLDPRT
48.0 x 48.0 x 33.4 mm

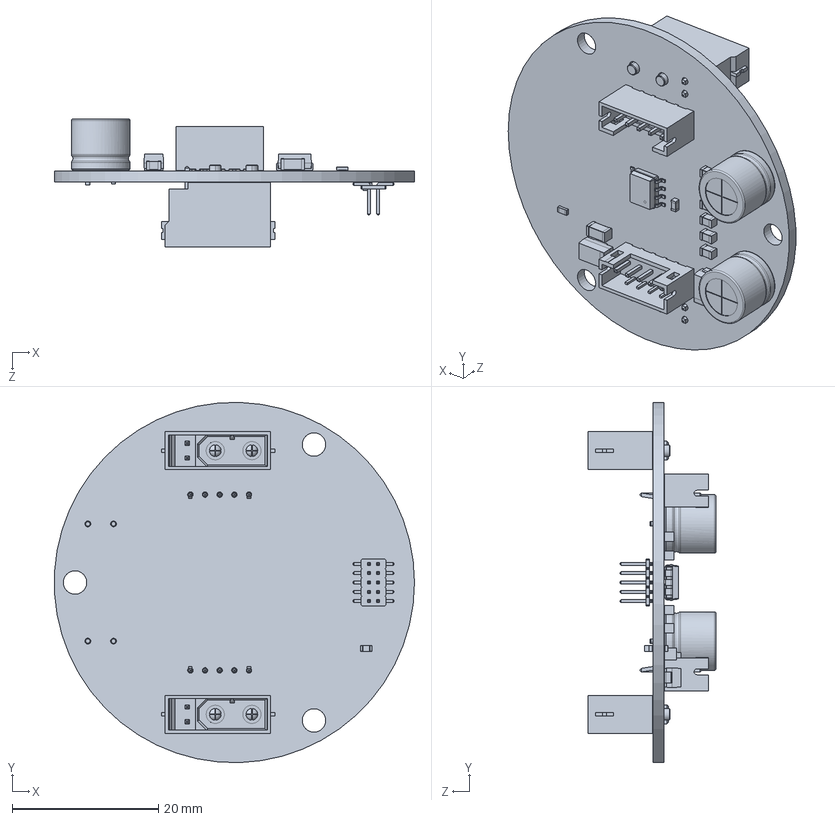
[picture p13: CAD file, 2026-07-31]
mechanical/source/interface_pcb.SLDPRT
49.2 x 49.2 x 17.5 mm

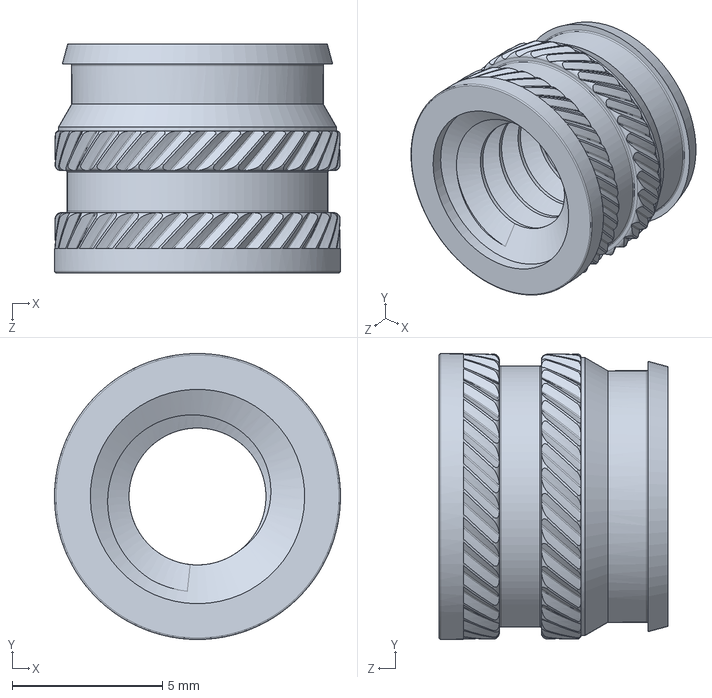
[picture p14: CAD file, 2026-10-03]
mechanical/source/93365A160_Brass Tapered Heat-Set Inserts for Plastic.SLDPRT
9.52 x 9.53 x 7.62 mm

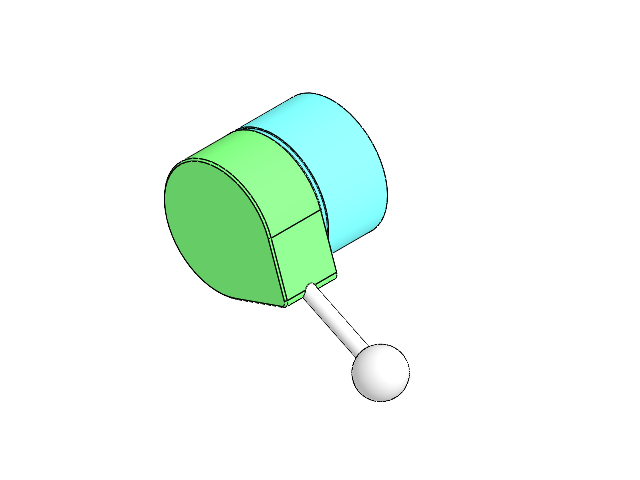
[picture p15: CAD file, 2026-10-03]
mechanical/source/actuator.SLDASM
interface_pcb
encodercover
base
mallet_holder
BL4825
mag_collar
magnet
stick
head
93365A160_Brass Tapered Heat-Set Inserts for Plastic

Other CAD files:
pcb/interface/interface2.SLDASM
mechanical/source/head.SLDPRT
mechanical/source/stick.SLDPRT
mechanical/source/magnet.SLDPRT
mechanical/source/base.SLDPRT
mechanical/source/encodercover.SLDPRT
mechanical/source/mallet_holder.SLDPRT
pcb/interface/interface.SLDASM
pcb/interface/interface.SLDPRT
pcb/interface/interface2.SLDPRT

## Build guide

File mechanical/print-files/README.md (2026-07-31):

# Ready-to-print exports

This folder currently contains AP214 STEP exports of the base, encoder cover,
and mallet holder generated by SolidWorks 2026. STEP preserves useful editable
geometry but does not encode verified slicer settings or print orientation.

Add revisioned STL or 3MF exports after confirming the actual printed
orientation and settings. Filenames should eventually include the part name and
revision, for example `base-r1.3mf`. Record the matching electronics/mechanical
revision and print settings in `mechanical/README.md` or a revision-specific
release note.

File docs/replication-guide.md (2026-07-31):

# Replication guide

This is the staged path toward reproducing the instrument. It distinguishes
verified repository content from information that still has to be supplied for
a released hardware revision.

## 1. Choose a known hardware revision

Do not order parts from the live KiCad working tree without first declaring
which controller modification and interface revision are known to match the
current firmware. A release package should contain a revisioned schematic, PCB,
BOM, placement file if applicable, fabrication archive, and assembly drawing.

Current design sources are in:

- `pcb/modchip/flexcircuit/` for the M2003 retrofit electronics.
- `pcb/interface/` for the interface electronics and related CAD.
- `MS51-M2003_pinmap.txt` for the controller pin-remapping work.

The proven hardware is currently a manual retrofit, not a replacement motor-
drive PCB. It starts with the integrated BL4818 drive board and replaces its
microcontroller, adds an INA180B2 shunt amplifier, changes several resistor
links, and adds a second cable assembly. Both cable assemblies terminate at the
custom encoder/interface board. See `docs/hardware.md` for the known high-level
architecture and the exact details still required before attempting the mods.

## 2. Build one actuator mechanically

A complete release needs editable CAD and print-ready exports for the three-
piece shell, mallet holder, encoder magnet holder, rest position, travel stops,
instrument mounting, and cable strain relief. Add the maintained files under
`mechanical/` using the conventions in its README. Build and validate a single
actuator before producing a batch.

The firmware assumes a 10-pole motor (five pole pairs), hall commutation, and a
14-bit MT6701 absolute encoder. Changing those assumptions requires reviewing
`include/m2003_config.h` and retuning the control system.

The current physical assembly sequence is:

1. Bolt the motor to the motor-side shell piece.
2. Slide the mallet holder over the motor bell.
3. Fit the magnet holder to the otherwise internal motor shaft.
4. Plug the modified drive-board cable assemblies into the custom MT6701 board.
5. Install the board and fasten the screw-on end cap.

This is an architecture description, not yet a complete assembly instruction;
orientations, clearances, fasteners, print settings, and cable routing must be
captured alongside the CAD and photographs.

## 3. Wire power, programming, and the ring

Before applying power, the released hardware documentation must state:

- supply voltage range, normal draw, peak draw, and recommended current limit;
- connector manufacturer/part number, pin numbering, polarity, and wire gauge;
- fuse, reverse-polarity, transient, and emergency-disconnect strategy;
- SWD programming connector pinout;
- ring TX/RX direction and the correct first/last-device connection.

The data link is 250,000 baud and uses Ring Bus Protocol v2. The host enumerates
the physical chain and assigns addresses 0 through 15. See `protocol.md` for
packet forwarding and the exact enumeration sequence.

## 4. Build and flash firmware

Follow `docs/firmware.md`. Flash with motor power disconnected where the
hardware allows it, verify the image, and inspect the board for unexpected heat
or current before connecting the mechanism.

## 5. Bring up one actuator

Use a current-limited supply and the command-line tool:

```powershell
py scripts/ring_tool.py -p COM7 enumerate
py scripts/ring_tool.py -p COM7 status 0
py scripts/ring_tool.py -p COM7 timing-status 0
```

Confirm sensor direction, encoder validity, current offset, phase order, fault
handling, and physical travel before homing. Then establish safe starting
values for homing duty, home offset, coast distance, strike current, and dead-
strike parameters. Persist settings only after repeated power-cycle tests.

## 6. Assemble and validate a ring

Add actuators one at a time. After each addition, enumerate repeatedly, query
every address, and inspect bus timing/error counts. Confirm that a faulted or
unpowered device behaves as expected for the chosen topology. One ring can
contain at most 16 addresses in the current protocol.

## 7. Configure the player

Follow `docs/host-software.md`. In the browser, map each enumerated slot to the
MIDI note played by its physical instrument. Validate timing with isolated
notes, chords, and fast repeated notes before playing an unrestricted MIDI
file. Save the instrument's mapping and calibration as deployment data, not as
unexplained source-code defaults.

## 8. Record the replica

For each built instrument, record controller and interface revisions, firmware
commit, power supply, actuator-to-note mapping, persisted tuning parameters,
known mechanical deviations, and the final bench-test results. This record is
what makes later repairs and additional batches reproducible.

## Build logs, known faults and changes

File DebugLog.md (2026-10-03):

# Debug Log

Bench-observed bugs and their resolutions. Structural decisions live in DECISIONS.md; this file is the bug breadcrumb trail.

## 2026-06-10 — Dead strike produced a double hit instead of one clean hit

- **Observation:** Dead strikes nearly worked with tuning, but the mallet audibly hit twice. User hypothesis (confirmed by code reading): the mallet has already begun rebounding before MUTING engages.
- **Root cause:** `src/strike.c` mute entry keyed off `maybe_record_impact()` — a zero-cross of the *filtered* velocity estimate (`vel_filt_q8` EMA in `src/motor.c`), sampled in `strike_tick` at 500 Hz. Filter group delay + 2 ms tick quantization meant the velocity-0 brake engaged after the ball tip had decompressed and launched; the brake stopped the mallet hovering off the surface and the press phase re-seated it from a gap → second tap.
- **Fix:** Two-stage position-armed trigger in `src/motor.c` (`motor_arm_coast_then_brake`): coast at the coast point, then engage the velocity-0 brake on the raw encoder crossing of the learned drum surface (± new `MUTE_ENGAGE_OFFSET` tunable, param 0x06), at the encoder sampling cadence — same proven path as coast arming, no filter or strike-tick lag. Filtered zero-cross retained only as the stalled-short fallback.
- **Class:** filtered-estimate-latency (control action keyed to a lagging derived signal instead of the raw measurement)
- **Recently-touched?** yes — mute entry written earlier the same session it was bench-tested.
- **Time to fix:** ~1 session (diagnosis was user-assisted from bench observation).

## 2026-08-03 — Chords clumped or dropped following MIDI notes

- **Observation:** A freshly updated 14-actuator handpan ring played isolated-note songs normally, but chord passages sometimes pulled a later note into the chord or lost several following notes. One captured play scheduled 278 events but attempted only 212, with 13 transport failures, one `REJECT_NOT_READY`, and 508.7 ms maximum serial wait.
- **Root cause:** In commit `c62435e`, `scripts/ring_midi_server.py:1088` grouped by compensated transmit time without requiring the same MIDI impact time, while `scripts/ring_midi_server.py:1142` synchronously collected chord replies; missing replies stalled the absolute-time worker. `player/midi_player.html:1983` then canceled the still-running worker 500 ms after nominal song duration.
- **Fix:** Require equal MIDI `t_ms` for chord membership, transmit playback chords with reply mode `NONE`, account for them as unacknowledged rather than accepted, and let server state exclusively determine natural completion.
- **Class:** blocking-reply-in-realtime-scheduler
- **Recently-touched?** yes — all three paths were introduced or changed with the chord synchronization work.
- **Time to fix:** one bench feedback cycle.
- **Hardware validation:** **PASS 2026-08-03** on the 14-actuator handpan; chords were nearly perfectly synchronized and rapid layered passages retained following notes cleanly.

## 2026-08-13 — Loose mallet mount allowed a runaway strike

- **Observation:** If a mallet mounting loosened and pushed the ball out of the drum path, a strike could spin the motor near top speed and sometimes throw the mallet or the ball. Homing also had no explicit travel/time ceiling, although its low duty was not energetic enough to throw hardware.
- **Root cause:** `src/strike.c` had no terminal condition based on total encoder travel in `STRIKE_DRIVING`, `STRIKE_COASTING`, `STRIKE_MUTING`, or `STRIKE_CATCHING`; those states assumed the learned drum contact/rebound would occur. `STRIKE_HOMING` likewise relied only on stall and settle detection. A displaced mechanical stop violated both assumptions.
- **Fix:** Accumulate absolute encoder travel for each active sequence at the existing 500 Hz strike cadence. Fault and disable PWM at one revolution for either homing or strike; add a 5-second homing backstop; invalidate homing on every motor fault and fault clear. Re-home position changes of at least 1,024 counts are now exposed as a warning, and an idle position hold can be paused safely while `SAVE_SETTINGS` persists the reference.
- **Class:** unbounded-mechanical-state-machine
- **Recently-touched?** no — the missing termination contract was longstanding; the bench observation exposed it.
- **Time to fix:** one session.
- **Hardware validation:** pending a restrained-actuator test of both limit faults, recovery/re-home, and the shifted-home warning.

## 2026-08-22 — First home after power-up falsely warned of a shifted drum

- **Observation:** Most actuators reported a home-shift warning on the first touch-off after power-up even though the drum surface had not moved; later homes in the same boot were generally consistent.
- **Root cause:** `src/encoder.c:163` seeds continuous position at zero from the arbitrary power-up rotor angle when no logical zero exists, while pre-fix `src/persist.c:185` saved that boot-relative drum position and pre-fix `src/strike.c:889` compared it after the next boot as though both values shared an origin.
- **Fix:** Capture and compare the raw 14-bit encoder angle at drum contact, persist it in record v5, and make v3/v4 migration establish a new baseline without warning.
- **Class:** boot-relative-coordinate-persisted-as-absolute
- **Recently-touched?** yes — the warning comparison was introduced in the latest firmware commit.

## 2026-09-20 — Microphone scan stalled on noise and skipped cached status

- **Observation:** Mobile scanning waited too long for ringdown in background city noise, skipped mallets for unavailable fresh state, and later stopped with a generic “Stopped before completion” row when no usable note was heard.
- **Root cause:** The newly added browser scan required return to the initial noise floor, treated every cached observation as unusable, and distinguished silence from unclear audio using onset alone. Background noise can satisfy onset without yielding a pitch. Final cleanup replaced the affected row's reason with a generic stopped label.
- **Fix:** Bound settling to 0.6–1.5 seconds, remeasure the pre-strike background, accept healthy recent cache observations and recheck stale status on the same mallet. Retry silence or unclear audio once, then continue unresolved. Bound extra current to 20% / 200 mA and 3000 mA total; overload retries at original current. Preserve actual command/readiness errors in the row and never retry an unacknowledged command.
- **Recently-touched?** yes — browser scan implementation in this session; firmware and bus protocol unchanged.
- **Validation:** 31 pitch/audio/workflow tests, 19 MIDI tests and 22 bridge/playback tests passed; forced firmware rebuild passed. Isolated browser simulation recovered a noise-only first attempt, exhausted two silent attempts on another slot, and finished with all nine audible notes detected. Physical validation of these revised behaviors remains pending.

## 2026-09-20 — Scan appeared stuck after hearing a strike

- **Observation:** The user intermittently saw “Heard the strike” without progress.
- **Root cause reproduced:** In `player/pitch_detector.js`, the fresh-audio guard returned before normal timeout checks when the AudioContext was interrupted or its clock froze. That left the last progress message visible until the 25-second fallback. Timer callback exceptions also escaped the capture promise.
- **Fix:** Add a wall-clock watchdog before that guard, attempt one audio resume at 0.75 seconds, and report stalled audio by three seconds. Do not dispatch further strikes without recent running audio. Route analyser exceptions into capture failure and preserve the existing retry behavior for ordinary unclear notes.
- **Recently-touched?** yes — the browser capture loop was edited in this session.
- **Validation:** Added regression cases for frozen audio immediately after onset, successful recovery with running/interrupted AudioContext states, and analyser exceptions. The two stall/recovery tests failed against the prior implementation and pass with the fix. All 34 pitch/audio/workflow tests pass. The physical cause on the user's phone is not yet confirmed.

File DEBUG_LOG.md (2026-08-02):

# Debug Log

## 2026-08-01 — Standard flash command omitted the new LDROM loader

- **Observation:** An actuator was flashed with `scripts/flash-jlink.ps1`, but that familiar command installed only APROM and its manifest rather than the newly required LDROM loader.
- **Root cause:** Pre-fix `scripts/flash-jlink.ps1:41` selected the app-only build, and pre-fix `Makefile:95` defined `build-jlink` without the LDROM image.
- **Fix:** Collapsed J-Link support to one standard build/flash path that programs and byte-verifies APROM, manifest, and LDROM while leaving CONFIG unchanged.
- **Class:** misleading-tool-entrypoint
- **Recently-touched?** yes
- **Time to fix:** about 20 minutes

## 2026-08-01 — Generic J-Link provisioning is slow

- **Observation:** Programming the complete APROM, manifest, and LDROM image through J-Link Commander takes substantially longer than flashing the same device with a CMSIS-DAP probe.
- **Root cause:** `scripts/make_provision_jlink.py:91` expands every non-erased 32-bit word into five debugger commands because the installed J-Link device database has no native M2003 flash algorithm. The complete image produces about 39,500 command-file lines; byte-for-byte PowerShell verification contributes only about 50 ms.
- **Resolution:** Leave the reliable single J-Link path unchanged for now. Meaningful acceleration would require either adopting the OpenOCD NuMicro flash driver with CMSIS-DAP or adding a RAM-resident page-programming stub for generic J-Link.
- **Class:** debugger-flash-command-overhead
- **Recently-touched?** yes
- **Time to diagnose:** about 20 minutes

## 2026-08-02 — Software boot handoff required destination VECMAP

- **Observation:** Early LDROM builds visibly entered the loader but did not reliably reach APROM, and application-requested loader entry could not be distinguished from a watchdog return.
- **Root cause:** Pre-fix `ldrom/main.c:73` and `src/boot_control.c:55` changed only the runtime boot-source bit before system reset; the M2003 vendor sequence also maps the destination vector page. Application entry additionally relied on ISP remaining enabled even though `src/persist.c:194` can close it.
- **Fix:** Both handoffs now enable ISP as needed, issue and verify destination VECMAP, verify the matching boot source, and system-reset; loader protocol 2 exposes retained reset/FMC state.
- **Class:** incomplete-boot-handoff-sequence
- **Recently-touched?** yes
- **Time to fix:** one extended research-and-bench session

## 2026-08-02 — LDROM alias caused false J-Link APROM verification failure

- **Observation:** Standard flashing repeatedly reported `APROM verify failed at +0x4: expected 0x19, got 0xC5` even though programming appeared to complete.
- **Root cause:** Pre-fix `scripts/flash-jlink.ps1:115` compared APROM against a debugger read beginning at CPU address zero, which aliases the active LDROM vector page in LDROM-first mode.
- **Fix:** The standard wrapper now reconstructs APROM `0x0000..0x01FF` through physical FMC reads and joins it with direct reads above the alias window before byte comparison.
- **Class:** debugger-address-alias
- **Recently-touched?** yes
- **Time to fix:** about 30 minutes

## 2026-08-02 — Post-reset enumeration consumed a delayed mode echo

- **Observation:** `RUN_APROM` succeeded, but the updater's immediate application check failed with `unexpected enumerate reply: 01`; a fresh connection then enumerated and queried the healthy application normally.
- **Root cause:** Pre-fix `scripts/ring_bus.py:719` read exactly one frame after sending `SET_ADDRESS`, while the preceding `ENTER_STORE_FORWARD` cut-through echo could arrive after the fixed 10 ms flush interval.
- **Fix:** Enumeration now waits for each mode-command echo and skips stale control or seed echoes until a valid nonzero address count returns.
- **Class:** fixed-delay-protocol-race
- **Recently-touched?** no
- **Time to fix:** about 10 minutes

## 2026-08-02 — Manifest-last recovery passed staged power-cycle testing

- **Observation:** The restrained actuator was deliberately power-cycled with (1) an erased manifest and intact APROM, (2) page 0 erased with only its first 32 bytes restored, and (3) a fully written and CRC-verified APROM whose manifest commit was withheld.
- **Result:** Every cold boot remained in a responsive, enumerable LDROM loader with no committed image and cleared volatile update state. The partial image returned `CRC_MISMATCH`; `RUN_APROM` with an invalid manifest returned `BAD_STATE`.
- **Recovery:** A normal version-2 update rewrote 54 pages, verified CRC `0x349FA335`, committed the manifest, re-enumerated the application, and preserved strike settings `1024 / 300 / 100`. The same image also passed the one-device `--all` command path.
- **Class:** recovery-validation
- **Recently-touched?** yes
- **Time to validate:** about 15 minutes of staged bench testing

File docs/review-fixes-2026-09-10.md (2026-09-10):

# Review fixes and validation — 2026-09-10

## Changes

- STOP removes drive while preserving a latched motor fault. CLEAR_FAULT is
  still required before another motion command can start the motor.
- Saved calibration uses the absolute drum-contact encoder angle and the home
  clearance (`home_offset`). Startup reconstructs runtime coordinates from the
  current encoder reading rather than restoring coordinates from an earlier
  boot. Restoring calibration does not start motion.
- The tuning tool attempts STOP when a run fails, including when a motion
  command's reply is lost, and closes the connection even if STOP also fails.
- Bus reply deadlines now expire even while unrelated frames keep arriving.

## Settings compatibility

New saves use settings version 6 with the existing flash-page locations and
record size. Versions 3 through 5 can be migrated when they contain an absolute
contact angle or enough information to recover it. Otherwise tuning is loaded
and a fresh home is required. Older firmware cannot read version 6 records.
Wire commands are unchanged.

The absolute encoder identifies position within one revolution. Startup selects
the nearest equivalent home; it cannot recover a previous boot's turn count.

## Validation

- `make -B images`: passed a forced firmware and loader rebuild. Application
  size: 29,572 bytes of text, 12 bytes of data, and 1,360 bytes of BSS.
- `python -m unittest discover -s tests -v` on Windows: 55 passed; the one native
  C test was skipped because native GCC is unavailable on that PC.
- `python3 tests/test_firmware_native.py` in an isolated copy on `music-pi`:
  passed using the Pi's native GCC. It executed production motor, strike, PID,
  and settings-record code with simulated peripherals, covering 50 reboot
  geometries, encoder wrap, both directions, legacy migration, and all six
  motor-fault latches.
- `python3 tests/test_review_regressions.py -q` in that same isolated copy:
  eight tests passed, covering bus deadlines and tuning-tool cleanup.
- `git diff --check`: passed. New and modified functions were reviewed for
  implementation completeness.

The update payload is `build/m2003-motor.update.bin`: 29,584 bytes, CRC32
`0xEBFDF9BC`. The raw application and manifest are also generated in `build/`.

## Instrument checks

Read-only status checks on the existing instrument reported 14 homed actuators
and inactive playback. Its installed firmware, live application files, and
running services were left unchanged. No motor-motion commands were sent.

Flashing is reserved for the owner. The native tests validate software behavior
with simulated peripherals; flash persistence, real encoder communication,
power-cycle restoration, and motor behavior with the new firmware still need
physical validation after flashing.

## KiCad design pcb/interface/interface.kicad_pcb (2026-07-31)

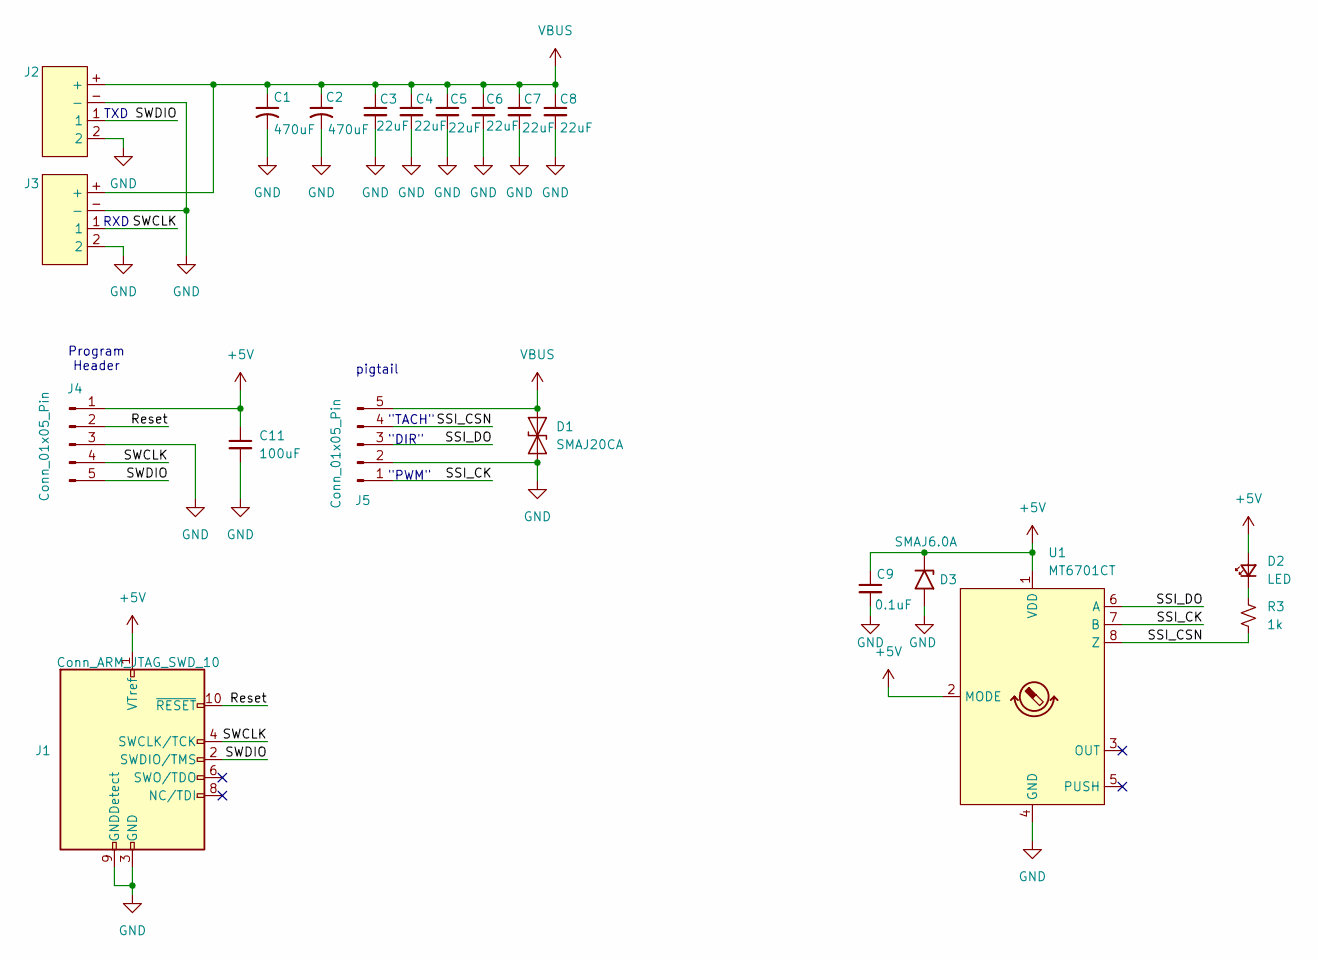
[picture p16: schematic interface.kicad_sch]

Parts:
C1, C2: 470uF; C_Radial_D8.0mm_H7.0mm_P3.50mm
C3, C4, C5, C6, C7, C8: 22uF; C_0805_2012Metric
C9: 0.1uF; C_0603_1608Metric
C11: 100uF; C_1206_3216Metric
D1: SMAJ20CA; D_SMA
D2: LED; LED_0603_1608Metric
D3: SMAJ6.0A; D_SMA
J1: Conn_ARM_JTAG_SWD_10; PinHeader_2x05_P1.27mm_Vertical_SMD
J2, J3: XT30(2+2)PB-M.G.B
J4, J5: Conn_01x05_Pin; JST_PH_B5B-PH-K_1x05_P2.00mm_Vertical
R3: 1k; R_0603_1608Metric
U1: MT6701CT; SO-8_3.9x4.9mm_P1.27mm

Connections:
+5V: C9.1, C11.1, D2.2 (A), D3.1 (A1), J1.1 (VTref), J4.1, U1.1 (VDD), U1.2 (MODE)
/Reset: J1.10 (~RESET), J4.2
/SSI_CK: J5.1, U1.7 (B)
/SSI_CSN: J5.4, R3.2, U1.8 (Z)
/SSI_DO: J5.3, U1.6 (A)
/SWCLK: J1.4 (SWCLK/TCK), J3.1, J4.4
/SWDIO: J1.2 (SWDIO/TMS), J2.1, J4.5
GND: C1.2, C2.2, C3.2, C4.2, C5.2, C6.2, C7.2, C8.2, C9.2, C11.2, D1.1 (A1), D3.2 (A2), J1.3 (GND), J1.5 (GND), J1.9 (GNDDetect), J2.2, J2.-, J3.2, J3.-, J4.3, J5.2, U1.4 (GND)
unnamed: D2.1 (K), R3.1
VBUS: C1.1, C2.1, C3.1, C4.1, C5.1, C6.1, C7.1, C8.1, D1.2 (A2), J2.+, J3.+, J5.5

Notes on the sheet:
RXD
pigtail
"TACH"
Program Header
"PWM"
"DIR"
TXD

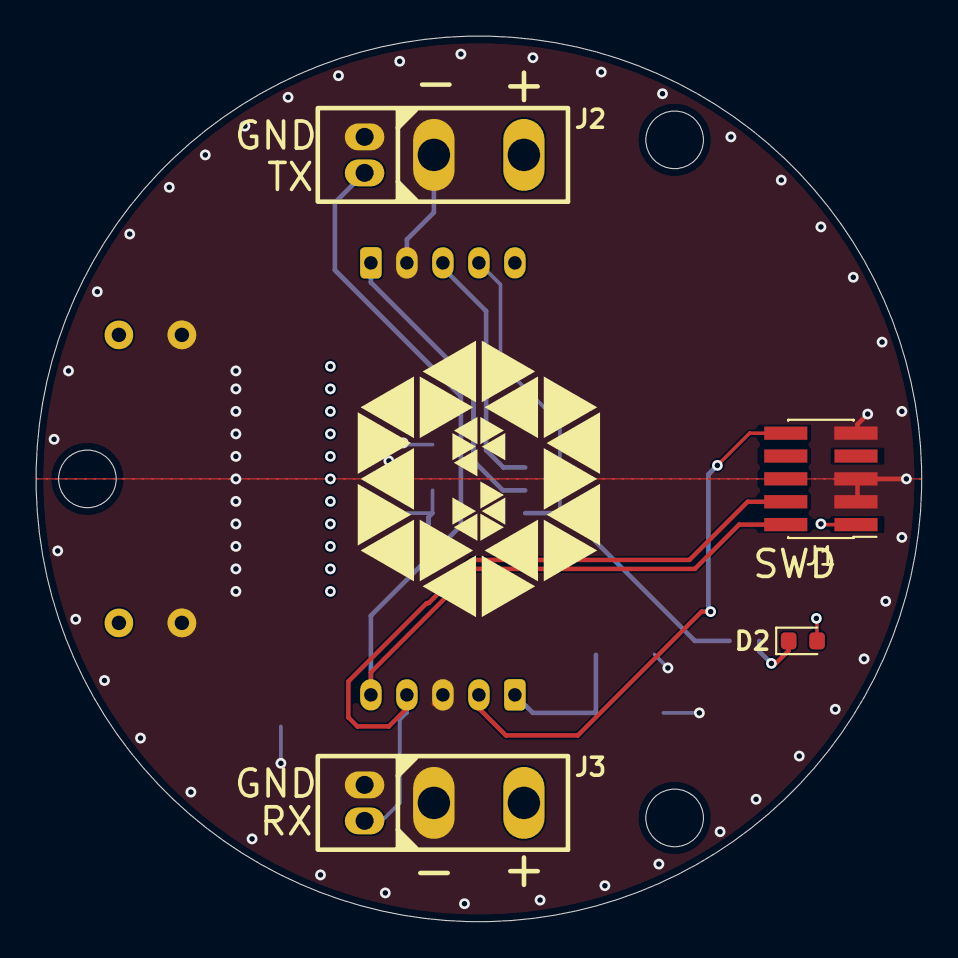
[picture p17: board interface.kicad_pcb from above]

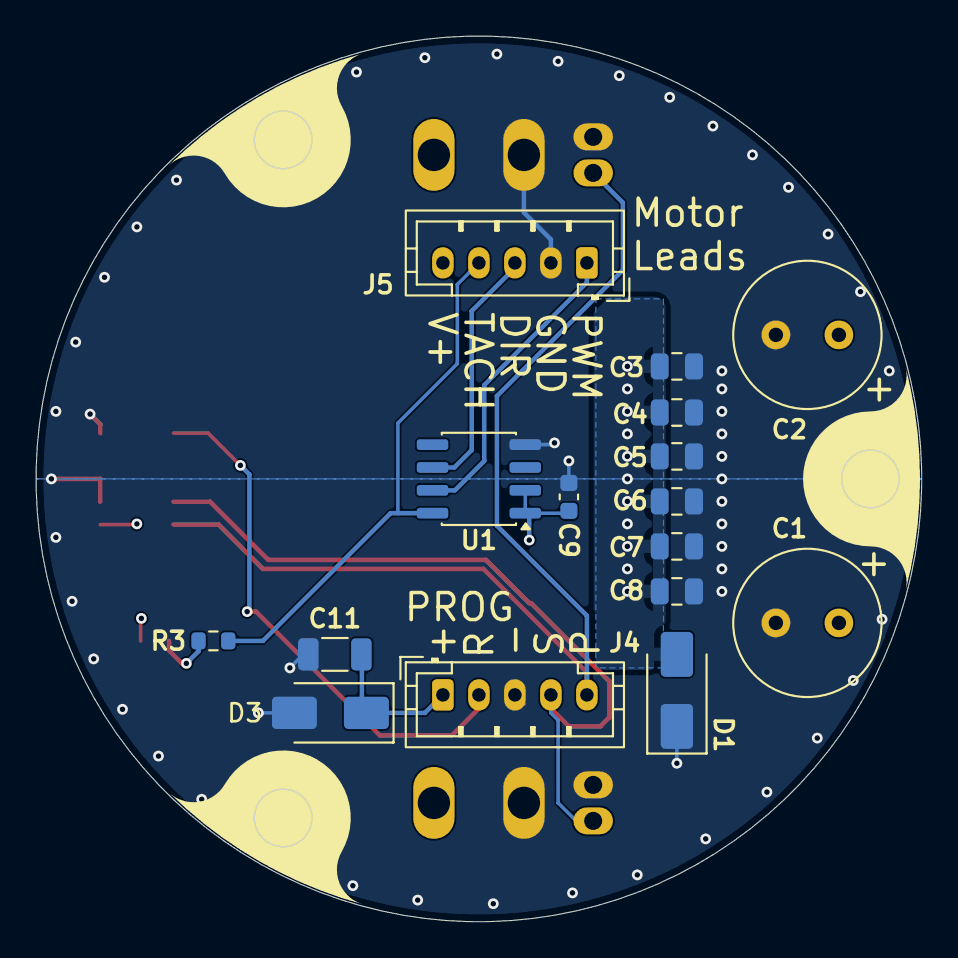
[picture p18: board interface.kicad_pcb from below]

Board: 4 copper layers, 49.2 x 49.2 mm, 20 parts (16 on the bottom side), 10 nets.

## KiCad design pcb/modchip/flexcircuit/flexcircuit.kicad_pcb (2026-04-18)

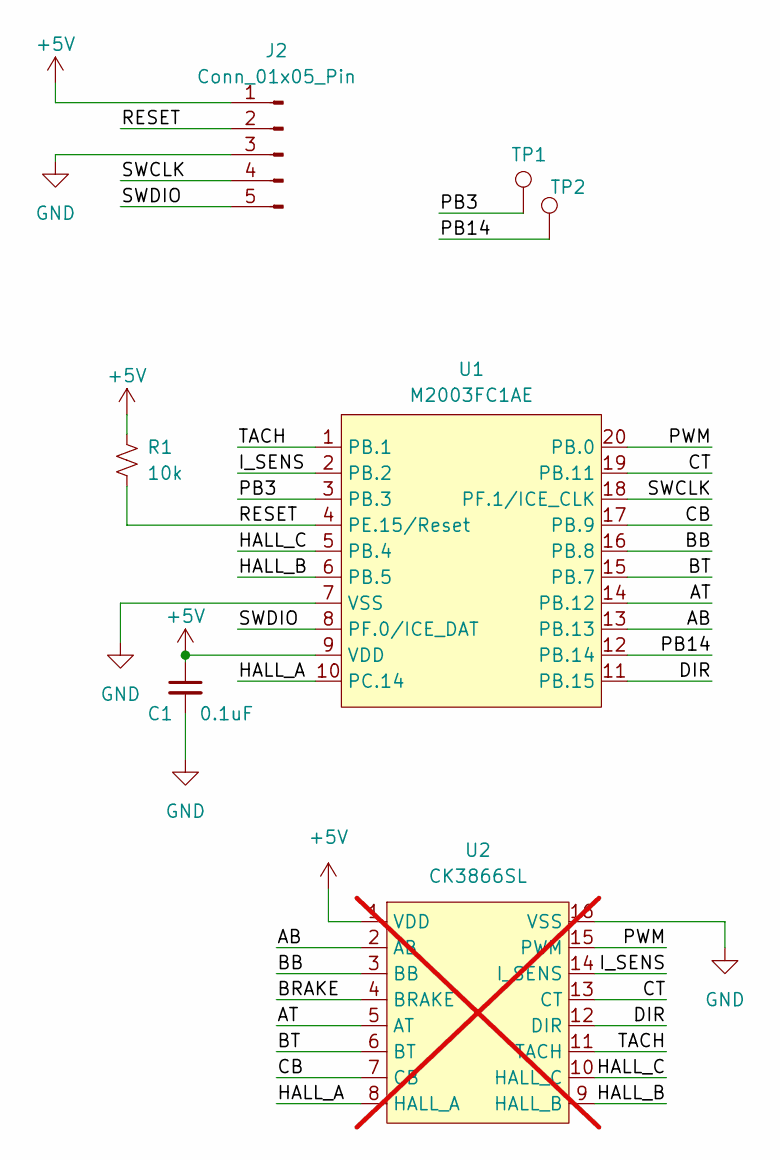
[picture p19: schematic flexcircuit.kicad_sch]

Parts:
C1: 0.1uF; C_0603_1608Metric
J2: Conn_01x05_Pin; JST_PH_B5B-PH-SM4-TB_1x05-1MP_P2.00mm_Vertical
R1: 10k; R_0603_1608Metric
TP1, TP2: TestPoint; TestPoint_Pad_D2.0mm
U1: M2003FC1AE; TSSOP-20_4.4x6.5mm_P0.65mm
U2: CK3866SL; SOIC-16_3.9x9.9mm_P1.27mm; not fitted

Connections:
+5V: C1.1, J2.1, R1.1, U1.9 (VDD), U2.1 (VDD)
/AB: U1.13 (PB.13), U2.2 (AB)
/AT: U1.14 (PB.12), U2.5 (AT)
/BB: U1.16 (PB.8), U2.3 (BB)
/BRAKE: U2.4 (BRAKE)
/BT: U1.15 (PB.7), U2.6 (BT)
/CB: U1.17 (PB.9), U2.7 (CB)
/CT: U1.19 (PB.11), U2.13 (CT)
/DIR: U1.11 (PB.15), U2.12 (DIR)
/HALL_A: U1.10 (PC.14), U2.8 (HALL_A)
/HALL_B: U1.6 (PB.5), U2.9 (HALL_B)
/HALL_C: U1.5 (PB.4), U2.10 (HALL_C)
/I_SENS: U1.2 (PB.2), U2.14 (I_SENS)
/PB3: TP1.1, U1.3 (PB.3)
/PB14: TP2.1, U1.12 (PB.14)
/PWM: U1.20 (PB.0), U2.15 (PWM)
/RESET: J2.2, R1.2, U1.4 (PE.15/Reset)
/SWCLK: J2.4, U1.18 (PF.1/ICE_CLK)
/SWDIO: J2.5, U1.8 (PF.0/ICE_DAT)
/TACH: U1.1 (PB.1), U2.11 (TACH)
GND: C1.2, J2.3, U1.7 (VSS), U2.16 (VSS)

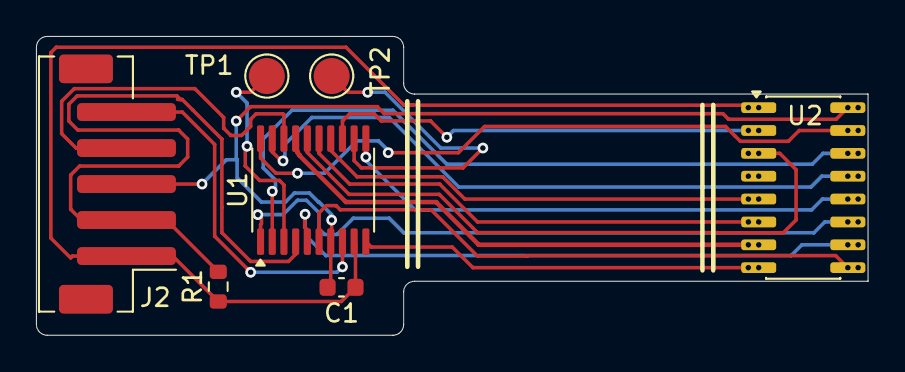
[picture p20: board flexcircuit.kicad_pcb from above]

Board: 2 copper layers, 46.2 x 16.6 mm, 7 parts (0 on the bottom side), 20 nets.

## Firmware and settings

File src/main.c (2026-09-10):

/*
 * Main Control Loop for Nuvoton M2003
 */

#include <stdint.h>
#include "m2003_config.h"
#include "M2003.h"
#include "wdt.h"
#include "app_pwm.h"
#include "app_uart.h"
#include "app_adc.h"
#include "hall.h"
#include "encoder.h"
#include "indicator.h"
#include "motor.h"
#include "persist.h"
#include "protocol.h"
#include "strike.h"
#include "timing.h"
#include "sched_util.h"
#include "boot_control.h"

extern uint32_t SystemCoreClock;
extern uint32_t CyclesPerUs;
extern uint32_t PllClock;

void Uart0DefaultMPF(void) {}

#define UART_BAUD              250000UL

static volatile uint32_t protocol_tick_count;
static uint32_t strike_tick_accum;
static uint32_t protocol_tick_accum;
static uint32_t indicator_tick_accum;
static uint32_t hall_baseline_divider;

/* Refresh the hall timing baseline once per second to prevent the
 * 24-bit delta in hall_process_transition from ever aliasing. */
#define HALL_BASELINE_REFRESH_PERIOD  CONTROL_LOOP_HZ

/* WDT liveness handshake: main loop sets this each iteration; SysTick only
 * kicks the watchdog when it is set, then clears it.  If either the main
 * loop or SysTick stalls for longer than the WDT timeout, the MCU resets
 * and the PWM braking handlers run on the boot path. */
static volatile uint8_t main_loop_alive;

static uint32_t schedule_protocol_timeout_from_control_ticks(uint32_t *accum,
                                                             uint32_t elapsed_control_ticks,
                                                             uint32_t *dropped_ticks)
{
    uint32_t extra_due;
    uint32_t total_due;
    uint32_t timeout_ticks;

    *accum += elapsed_control_ticks * PROTOCOL_TICK_HZ;
    if (*accum < CONTROL_LOOP_HZ) {
        if (dropped_ticks != 0u)
            *dropped_ticks = 0u;
        return 0u;
    }

    *accum -= CONTROL_LOOP_HZ;
    extra_due = *accum / CONTROL_LOOP_HZ;
    *accum -= extra_due * CONTROL_LOOP_HZ;
    total_due = 1u + extra_due;
    timeout_ticks = HZ_TICKS_FROM_MS(PROTOCOL_TICK_HZ, PROTOCOL_FRAME_TIMEOUT_MS);

    if (total_due > timeout_ticks) {
        if (dropped_ticks != 0u)
            *dropped_ticks = total_due - timeout_ticks;
        return timeout_ticks;
    }

    if (dropped_ticks != 0u)
        *dropped_ticks = 0u;

    return total_due;
}

static void clock_init(void)
{
    CLK->PWRCTL |= CLK_PWRCTL_HIRCEN_Msk;
    while (!(CLK->STATUS & CLK_STATUS_HIRCSTB_Msk)) {
    }

    CLK->CLKSEL0 = (CLK->CLKSEL0 & ~CLK_CLKSEL0_HCLKSEL_Msk) | CLK_CLKSEL0_HCLKSEL_HIRC;
    CLK->CLKDIV0 = (CLK->CLKDIV0 & ~CLK_CLKDIV0_HCLKDIV_Msk) | CLK_CLKDIV0_HCLK(1);

    CLK->AHBCLK |= CLK_AHBCLK_GPBCKEN_Msk | CLK_AHBCLK_GPCCKEN_Msk |
                   CLK_AHBCLK_GPECKEN_Msk | CLK_AHBCLK_GPFCKEN_Msk;

    SystemCoreClock = CLK_HIRC_24M;
    PllClock = CLK_HIRC_24M;
    CyclesPerUs = CLK_HIRC_24M / 1000000UL;

    timing_init();
    SysTick_Config(SystemCoreClock / CONTROL_LOOP_HZ);
    NVIC_SetPriority(SysTick_IRQn, 2u);
}

static void watchdog_init(void)
{
    /* WDT runs from LIRC (~10 kHz), so 2^14 clocks ≈ 1.6 s — comfortably
     * longer than the worst-case blocking op on this MCU (flash erase is
     * ~20 ms with IRQs disabled) and still fast enough to rescue a runaway. */
    CLK->PWRCTL |= CLK_PWRCTL_LIRCEN_Msk;
    while (!(CLK->STATUS & CLK_STATUS_LIRCSTB_Msk)) {
    }

    CLK->CLKSEL1 = (CLK->CLKSEL1 & ~CLK_CLKSEL1_WDTSEL_Msk) | CLK_CLKSEL1_WDTSEL_LIRC;
    CLK->APBCLK0 |= CLK_APBCLK0_WDTCKEN_Msk;

    WDT_Open(WDT_TIMEOUT_2POW14, WDT_RESET_DELAY_18CLK, TRUE, FALSE);
}

static void bod_init(void)
{
    /* Brown-out threshold 2.7 V: well below the 3.3 V nominal rail so normal
     * strike-current sag won't false-trigger, but high enough that the MCU is
     * still comfortably inside its 1.8 V operating window when we trip.  On
     * trip the chip goes through a clean reset — Reset_Handler → pwm_init
     * masks all phases — so the bridge lands in a safe state. */
    SYS_SET_BOD_LEVEL(SYS_BODCTL_BODVL_2_7V);
    SYS_ENABLE_BOD_RST();
    SYS_ENABLE_BOD();
}

/*
 * HardFault / NMI handlers: brake the PWM bridge immediately (direct register
 * writes — no function calls in case the stack is corrupted) and force a
 * system reset.  The WDT is the backstop if even this path can't run.
 */
static inline void fault_brake_pwm(void)
{
    PWM0->CNTEN = 0u;
    PWM0->MSKEN = 0x3Fu;
    PWM0->MSK   = 0x00u;
}

void HardFault_Handler(void)
{
    fault_brake_pwm();
    NVIC_SystemReset();
    while (1) { }
}

void NMI_Handler(void)
{
    fault_brake_pwm();
    NVIC_SystemReset();
    while (1) { }
}

void SysTick_Handler(void)
{
    uint32_t timing_start = timing_capture_stamp();
    uint32_t dropped_updates;
    uint32_t dropped_ticks;
    uint32_t protocol_ticks;

    /* Kick WDT only when the main loop has set its liveness flag since the
     * last tick — this way a hung main loop still trips the watchdog. */
    if (main_loop_alive != 0u) {
        main_loop_alive = 0u;
        WDT_RESET_COUNTER();
    }

    if (++hall_baseline_divider >= HALL_BASELINE_REFRESH_PERIOD) {
        hall_baseline_divider = 0u;
        hall_refresh_baseline();
    }

    /* Motor-control cadence follows actual PWM/ADC samples internally, but
     * housekeeping must continue when STOP masks PWM and ADC triggers cease. */
    (void)motor_tick_control();

    if (schedule_latest_from_control_ticks(&strike_tick_accum, 1u,
                                           STRIKE_LOOP_HZ, &dropped_updates)) {
        if (dropped_updates != 0u)
            timing_note_strike_drops(dropped_updates);
        strike_tick();
    }

    if (schedule_latest_from_control_ticks(&indicator_tick_accum, 1u,
                                           INDICATOR_TICK_HZ, &dropped_updates)) {
        indicator_tick();
    }

    protocol_ticks = schedule_protocol_timeout_from_control_ticks(&protocol_tick_accum,
                                                                  1u,
                                                                  &dropped_ticks);
    if (protocol_ticks != 0u) {
        if (dropped_ticks != 0u)
            timing_note_protocol_drops(dropped_ticks);
        protocol_tick_count += protocol_ticks;
    }

    timing_record_control_tick(timing_start);
}

int main(void)
{
    uint32_t handled_protocol_ticks = 0;

    SYS_UnlockReg();

    bod_init();
    clock_init();
    pwm_init();
    adc_init();
    hall_init();
    encoder_init();
    uart_init(UART_BAUD);
    protocol_init();
    motor_init();
    strike_init();
    persist_init();

    /* Auto-detect SSI CSn polarity if it isn't already known.  Probes both
     * polarities and validates via the MT6701 frame CRC; the right polarity
     * passes uniquely.  On success, save so future boots skip the probe. */
    {
        uint8_t learned_polarity = 0u;

        if (!encoder_has_csn_polarity())
            learned_polarity = encoder_autodetect_csn_polarity();
        if (encoder_has_csn_polarity()) {
            encoder_poll();
            persist_restore_calibration();
        }
        /* Capture only after restoring calibration so autodetection does not
         * overwrite a valid saved home with the startup unhomed state. */
        if (learned_polarity)
            (void)persist_save_runtime();
    }

    indicator_init();

    adc_irq_enable();

    /* Capture the INA180 zero-current offset while all phases are still
     * masked off (motor_init does not start driving).  ~64 samples at
     * 20 kHz is ~3.2 ms of averaging — plenty to average out LSB noise. */
    adc_calibrate_current_offset(64u);

    /* Enable watchdog last so any earlier initialisation blocking is
     * covered by the startup window instead of the WDT timeout. */
    watchdog_init();

    SYS_LockReg();

    while (1) {
        uint32_t protocol_poll_start;
        uint32_t pending_protocol_ticks;

        main_loop_alive = 1u;

        protocol_poll_start = timing_capture_stamp();
        protocol_poll();
        timing_record_protocol_poll(protocol_poll_start);

        if (boot_control_pending())
            boot_control_enter();

        pending_protocol_ticks = protocol_tick_count - handled_protocol_ticks;
        timing_note_protocol_backlog(pending_protocol_ticks);

        if (pending_protocol_ticks != 0u) {
            handled_protocol_ticks = protocol_tick_count;
            protocol_tick(pending_protocol_ticks);
        }
    }
}

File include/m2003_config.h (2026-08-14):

/*
 * M2003 Hardware Configuration (Pin-Compatible with MS51 Board)
 *
 * This header maps the physical pins of the BL4818 board to M2003 peripherals.
 */

#ifndef M2003_CONFIG_H
#define M2003_CONFIG_H

/* CPU Clock */
#define CLK_HIRC_24M        24000000UL

/* ── PWM Gate Drives (EPWM0) ────────────────────────────────────────────── */
/* EPWM0 channels 0-5 map to the 6 MOSFET gates. */
/* M2003 TSSOP20 pin mapping: */
#define PIN_PWM_U_LOW       PB13      /* PB.13, Pin 13, EPWM0_CH0 */
#define PIN_PWM_U_HIGH      PB12      /* PB.12, Pin 14, EPWM0_CH1 */
#define PIN_PWM_V_HIGH      PB7       /* PB.7, Pin 15, EPWM0_CH2 */
#define PIN_PWM_V_LOW       PB8      /* PB.8, Pin 16, EPWM0_CH3 */
#define PIN_PWM_W_LOW       PB9      /* PB.9, Pin 17, EPWM0_CH4 */
#define PIN_PWM_W_HIGH      PB11      /* PB.11, Pin 19, EPWM0_CH5 */

/* PWM Scaling */
#define PWM_FREQ_HZ         20000
#define PWM_PERIOD          (CLK_HIRC_24M / PWM_FREQ_HZ)
#define PWM_MAX_DUTY        1200    /* 24MHz / 20kHz */

/* ── UART Ring (UART1) ─────────────────────────────────────────────────── */
#define PIN_UART1_TX        PF0     /* Pin 8  */
#define PIN_UART1_RX        PF1     /* Pin 18 */

/* ── ADC Sensing ───────────────────────────────────────────────────────── */
#define ADC_CH_CURRENT      2       /* PB.2, Pin 2 */
#define ADC_CH_VOLTAGE      3       /* PB.3, Pin 3 */

/* ── SSI Encoder (Bit-Banged) ──────────────────────────────────────────── */
#define PIN_SSI_CLK         PB0       /* PB.0, Pin 20 (direct drive) */
#define PIN_SSI_CSN         PB1       /* PB.1, Pin 1 (inverted via N-FET) */
#define PIN_SSI_DAT         PB15      /* PB.15, Pin 11 */

/* ── Commutation ──────────────────────────────────────────────────────── */
#define COMMUTATION_OFFSET  1       /* Advance commutation by 1 sector (matches MS51 tuning) */
#define HALL_MIN_TRANSITION_US 20   /* reject implausibly fast hall chatter / edge bounce */

/* ── Motor Parameters ─────────────────────────────────────────────────── */
#define MOTOR_POLE_PAIRS    5       /* 10-pole, 12 slot outrunner */
#define HALL_TRANSITIONS_PER_REV (6 * MOTOR_POLE_PAIRS)  /* 30 */
#define ENCODER_COUNTS_PER_REV  16384   /* 14-bit absolute encoder */

/* ── Loop Rates ──────────────────────────────────────────────────────── */
#define CURRENT_LOOP_HZ     6000   /* fastest software loop: ADC/protection/current PI */
#define VELOCITY_LOOP_HZ    1500    /* velocity estimator + velocity PID               */
#define POSITION_LOOP_HZ    1000    /* position PID (outermost)                        */
#define STRIKE_LOOP_HZ      500    /* strike state machine                            */
#define PROTOCOL_TICK_HZ    500    /* serial parser timeout aging                     */
#define PROTOCOL_FRAME_TIMEOUT_MS 20u
#define INDICATOR_TICK_HZ   100u    /* status LED pattern step rate                    */
#define ENCODER_POLL_HZ     VELOCITY_LOOP_HZ /* bit-banged SSI read rate            */
#define CONTROL_LOOP_HZ     CURRENT_LOOP_HZ  /* SysTick fast tick budget/reporting   */

/* ── Timing Helpers ──────────────────────────────────────────────────── */
#define HZ_TICKS_FROM_MS(hz, ms) \
    ((uint32_t)((((uint64_t)(hz) * (uint64_t)(ms)) + 999ULL) / 1000ULL))
#define HZ_TICKS_FROM_US(hz, us) \
    ((uint32_t)((((uint64_t)(hz) * (uint64_t)(us)) + 999999ULL) / 1000000ULL))
#define VALUE_PER_TICK_FROM_HZ(hz, per_second) \
    ((uint32_t)((((uint64_t)(per_second)) + (uint64_t)(hz) - 1ULL) / (uint64_t)(hz)))

#if VELOCITY_LOOP_HZ > CONTROL_LOOP_HZ
#error "VELOCITY_LOOP_HZ must be <= CONTROL_LOOP_HZ"
#endif

#if POSITION_LOOP_HZ > CONTROL_LOOP_HZ
#error "POSITION_LOOP_HZ must be <= CONTROL_LOOP_HZ"
#endif

#if STRIKE_LOOP_HZ > CONTROL_LOOP_HZ
#error "STRIKE_LOOP_HZ must be <= CONTROL_LOOP_HZ"
#endif

#if PROTOCOL_TICK_HZ > CONTROL_LOOP_HZ
#error "PROTOCOL_TICK_HZ must be <= CONTROL_LOOP_HZ"
#endif

#if INDICATOR_TICK_HZ > CONTROL_LOOP_HZ
#error "INDICATOR_TICK_HZ must be <= CONTROL_LOOP_HZ"
#endif

#if ENCODER_POLL_HZ != VELOCITY_LOOP_HZ
#error "Bit-banged SSI encoder polling is expected to match VELOCITY_LOOP_HZ"
#endif

/* ── ADC / Current Sense ─────────────────────────────────────────────── */
#define ADC_FULL_SCALE_COUNTS        4095UL
#define ADC_VREF_MV                  5000UL
#define CURRENT_SENSE_SHUNT_MOHM     20UL
#define CURRENT_SENSE_GAIN           50UL
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

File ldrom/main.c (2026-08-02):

#include <stdint.h>
#include "M2003.h"
#include "boot_mailbox.h"
#include "firmware_image.h"
#include "bl_internal.h"

static bl_boot_diagnostics_t boot_diagnostics;

static uint8_t take_boot_request(uint8_t *address)
{
    volatile boot_mailbox_t *mailbox =
        (volatile boot_mailbox_t *)FIRMWARE_BOOT_MAILBOX_BASE;
    uint32_t magic = mailbox->magic;
    uint32_t magic_inverse = mailbox->magic_inverse;
    uint8_t requested_address = mailbox->address;
    uint8_t requested_inverse = mailbox->address_inverse;

    mailbox->magic = 0u;
    mailbox->magic_inverse = 0u;
    __DSB();

    if (magic != BOOT_MAILBOX_MAGIC ||
        magic_inverse != ~BOOT_MAILBOX_MAGIC ||
        requested_address > 15u ||
        requested_inverse != (uint8_t)~requested_address)
        return 0u;

    *address = requested_address;
    return 1u;
}

static uint8_t application_valid(void)
{
    const firmware_manifest_t *manifest =
        (const firmware_manifest_t *)FIRMWARE_MANIFEST_BASE;
    uint32_t initial_stack;
    uint32_t reset_vector;
    uint32_t reset_address;

    if (manifest->magic != FIRMWARE_MANIFEST_MAGIC ||
        manifest->format_version != FIRMWARE_MANIFEST_VERSION ||
        manifest->header_size != FIRMWARE_MANIFEST_SIZE ||
        manifest->image_size < 8u ||
        manifest->image_size > FIRMWARE_APP_LIMIT ||
        (manifest->image_size & 3u) != 0u ||
        manifest->flags != 0u ||
        manifest->reserved != 0u)
        return 0u;

    if (bl_crc32(manifest, FIRMWARE_MANIFEST_SIZE - sizeof(uint32_t)) !=
        manifest->manifest_crc32)
        return 0u;

    if (bl_flash_read_word(FIRMWARE_APROM_BASE, &initial_stack) != 0 ||
        bl_flash_read_word(FIRMWARE_APROM_BASE + 4u, &reset_vector) != 0)
        return 0u;

    if (initial_stack < FIRMWARE_SRAM_BASE ||
        initial_stack > FIRMWARE_BOOT_MAILBOX_BASE ||
        (initial_stack & 3u) != 0u)
        return 0u;

    reset_address = reset_vector & ~1u;
    if ((reset_vector & 1u) == 0u || reset_address < 8u ||
        reset_address >= manifest->image_size)
        return 0u;

    return (bl_crc32((const void *)FIRMWARE_APROM_BASE,
                     manifest->image_size) == manifest->image_crc32) ? 1u : 0u;
}

static int reset_to_application(void)
{
    uint32_t primask = __get_PRIMASK();

    __disable_irq();
    if (bl_flash_map_vectors(FIRMWARE_APROM_BASE) != 0)
        goto restore_loader;

    FMC_SET_APROM_BOOT();
    __DSB();

    if ((FMC->ISPCTL & FMC_ISPCTL_BS_Msk) != 0u)
        goto restore_loader;

    bl_uart_disable();
    __ISB();
    NVIC_SystemReset();
    for (;;) {
    }

restore_loader:
    if (bl_flash_map_vectors(FIRMWARE_LDROM_BASE) != 0) {
        for (;;) {
        }
    }
    FMC_SET_LDROM_BOOT();
    __DSB();
    __ISB();
    if (primask == 0u)
        __enable_irq();
    return -1;
}

static void restore_loader_vectors(void)
{
    if (bl_flash_map_vectors(FIRMWARE_LDROM_BASE) != 0) {
        __disable_irq();
        NVIC_SystemReset();
        for (;;) {
        }
    }
}

int main(void)
{
    uint8_t requested_address = 0xFFu;
    uint8_t requested;
    uint8_t valid;

    boot_diagnostics.reset_status = SYS->RSTSTS;
    bl_clock_init();
    boot_diagnostics.isp_control = FMC->ISPCTL;
    boot_diagnostics.isp_status = FMC->ISPSTS;
    bl_flash_init();
    requested = take_boot_request(&requested_address);

    if (bl_flash_map_vectors(FIRMWARE_APROM_BASE) != 0)
        valid = 0u;
    else
        valid = application_valid();

    restore_loader_vectors();
    bl_uart_init();
    bl_protocol_init(requested_address, valid, requested, &boot_diagnostics);

    if (requested == 0u && valid != 0u) {
        uint32_t elapsed_ms = 0u;

        SysTick->LOAD = 24000u - 1u;
        SysTick->VAL = 0u;
        SysTick->CTRL = SysTick_CTRL_CLKSOURCE_Msk | SysTick_CTRL_ENABLE_Msk;
        while (elapsed_ms < BL_BOOT_WINDOW_MS &&
               bl_protocol_hold_requested() == 0u) {
            bl_protocol_poll();
            bl_watchdog_service();
            if ((SysTick->CTRL & SysTick_CTRL_COUNTFLAG_Msk) != 0u)
                elapsed_ms++;
        }
        SysTick->CTRL = 0u;
        if (bl_protocol_hold_requested() == 0u) {
            bl_uart_flush();
            (void)reset_to_application();
        }
    }

    for (;;) {
        bl_protocol_poll();
        bl_watchdog_service();
        if (bl_protocol_run_requested() != 0u) {
            bl_uart_flush();
            (void)reset_to_application();
        }
    }
}

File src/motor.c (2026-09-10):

/*
 * Motor Control for Nuvoton M2003
 *
 * Supports three control modes:
 *   CTRL_DUTY     — open-loop signed duty cycle (torque-clamped)
 *   CTRL_VELOCITY — closed-loop RPM: velocity PID → current PI → duty
 *   CTRL_POSITION — cascaded: position PID → velocity PID → current PI → duty
 *
 * Loop rates are configured in m2003_config.h (_LOOP_HZ defines).
 * The fast tick runs at CURRENT_LOOP_HZ for current PI and protection, while
 * velocity and position work are scheduled more slowly from it.
 * ADC ISR oversamples at PWM rate and hands the fast loop an averaged window.
 */

#include <stdint.h>
#include "m2003_config.h"
#include "M2003.h"
#include "motor.h"
#include "pid.h"
#include "app_pwm.h"
#include "app_adc.h"
#include "commutation.h"
#include "hall.h"
#include "encoder.h"
#include "timing.h"
#include "irq_util.h"
#include "sched_util.h"

/* ── State ────────────────────────────────────────────────────────────── */
static motor_state_t state;
static fault_code_t  fault;
static ctrl_mode_t   ctrl_mode;

static int32_t       target_duty;
static int32_t       target_velocity;   /* signed RPM (set directly or by pos PID) */
static int32_t       target_position;   /* encoder counts, continuous */
static int32_t       target_current;    /* signed mA (CTRL_TORQUE mode) */
static int32_t       measured_velocity;  /* signed RPM */
static int8_t        drive_dir;          /* +1 / -1, commutation direction */
static uint32_t      torque_limit_ma;
static uint32_t      current_ma;
static int32_t       current_filt_q8;    /* filtered current estimate in Q8 mA */
static uint8_t       current_filt_initialized;
static uint16_t      overcurrent_samples;
static uint16_t      peak_overcurrent_samples;

static int32_t       prev_enc_position;
static int32_t       vel_filt_q8;       /* IIR-filtered velocity in Q8 */
static uint8_t       vel_initialized;

static int32_t       last_enc_pos_seen;   /* encoder position observed at last motion */
static uint32_t      enc_stall_samples;   /* PWM samples since last observed motion */
static uint8_t       adc_silent_ticks;    /* consecutive fast ticks with zero ADC samples */
static uint16_t      idle_encoder_divider;/* velocity ticks skipped while not in MOTOR_RUN */

static int32_t       last_applied_duty;  /* for bumpless transfer on mode switch */
static uint8_t       coasting;           /* 1 = phases floating, skip duty dispatch */
static int32_t       coast_trip_pos;     /* auto-coast position threshold */
static int8_t        coast_trip_dir;     /* +1: coast when pos >= trip, -1: when <= */
static uint8_t       coast_armed;        /* 1 = watching for coast trigger on encoder samples */
static int32_t       brake_trip_pos;     /* dead strike: velocity-0 brake position threshold */
static uint8_t       brake_stage;        /* 0 = none, 1 = brake follows coast, 2 = brake armed */
static uint8_t       brake_engaged;      /* latched when brake stage tripped */
static pid_t         vel_pid;
static pid_t         pos_pid;
static pid_t         cur_pid;
static int32_t       current_setpoint;   /* mA, output of velocity PID for current loop */
static uint32_t      velocity_sched_accum;
static uint32_t      position_sched_accum;
static uint32_t      velocity_elapsed_samples;

/*
 * Encoder-based velocity:
 *   RPM = delta_counts * 60 * PWM_FREQ_HZ /
 *         (ENCODER_COUNTS_PER_REV * elapsed_pwm_samples)
 */
/* ── Helpers ─────────────────────────────────────────────────────────── */

static void reset_scheduler_state(void)
{
    velocity_sched_accum = 0u;
    position_sched_accum = 0u;
    velocity_elapsed_samples = 0u;
}

static int32_t estimate_velocity(uint32_t elapsed_samples)
{
    int32_t pos = encoder_get_position();
    int32_t delta = pos - prev_enc_position;
    prev_enc_position = pos;

    if (!vel_initialized) {
        vel_initialized = 1;
        return 0;
    }

    /* A healthy fast loop accumulates several ADC samples between velocity
     * ticks.  Zero here means ADC has gone silent — motor_tick_control's
     * FAULT_ADC_TIMEOUT detector should have caught it first; treat this
     * as a belt-and-braces fallback rather than silently dividing. */
    if (elapsed_samples == 0u)
        return measured_velocity;

    /* RPM = delta * 60 * PWM_FREQ_HZ / (ENCODER_COUNTS_PER_REV * elapsed)
     *
     * Negate: encoder counts positive in opposite direction to commutation forward.
     * All 32-bit arithmetic — the numerator fits for |delta| < 1789 (>14 000 RPM),
     * well beyond this motor's operating range.  Avoids a 64-bit software divide
     * (~300 cycles on Cortex-M23) that ran every velocity tick. */
    int32_t raw_rpm = (-delta * (int32_t)(60 * PWM_FREQ_HZ)) /
                      ((int32_t)ENCODER_COUNTS_PER_REV * (int32_t)elapsed_samples);

    /* First-order IIR in Q8 for sub-RPM precision */
    int32_t raw_q8 = raw_rpm << PID_SCALE_SHIFT;
    /* Use division to avoid asymmetric deadband and -1 RPM stuck state with signed shift */
    vel_filt_q8 += (raw_q8 - vel_filt_q8) / (1 << VEL_FILTER_SHIFT);

    return vel_filt_q8 / PID_SCALE;
}

static int32_t run_velocity_loop(void)
{
    return pid_update(&vel_pid, target_velocity, measured_velocity);
}

static void apply_duty(int32_t duty)
{
    uint32_t abs_duty;
    int8_t new_dir;
    last_applied_duty = duty;

    if (duty >= 0) {
        new_dir = 1;
        abs_duty = (uint32_t)duty;
    } else {
        new_dir = -1;
        abs_duty = (uint32_t)(-duty);
    }

    if (abs_duty > PWM_MAX_DUTY)
        abs_duty = PWM_MAX_DUTY;

    /* Update commutation immediately on direction change — otherwise
     * the motor runs on a stale phase pattern until the next hall
     * transition, which may never come if the motor is near standstill. */
    if (new_dir != drive_dir) {
        drive_dir = new_dir;
        commutation_update(drive_dir);
    }

    pwm_set_duty((uint16_t)abs_duty);
}

static int32_t torque_clamp(int32_t duty)
{
    if (current_ma <= torque_limit_ma)
        return duty;

    return (duty * (int32_t)torque_limit_ma) / (int32_t)current_ma;
}

static int32_t run_current_loop(int32_t setpoint_ma)
{
    int32_t magnitude;
    int32_t duty;

    /* Clamp to torque envelope */
    if (setpoint_ma > (int32_t)torque_limit_ma)
        setpoint_ma = (int32_t)torque_limit_ma;
    else if (setpoint_ma < -(int32_t)torque_limit_ma)
        setpoint_ma = -(int32_t)torque_limit_ma;

    /* Current PI operates on magnitude — shunt measures unsigned current */
    magnitude = (setpoint_ma >= 0) ? setpoint_ma : -setpoint_ma;
    duty = pid_update(&cur_pid, magnitude, (int32_t)current_ma);

    return (setpoint_ma >= 0) ? duty : -duty;
}

static void reset_current_protection_state(void)
{
    current_filt_q8 = 0;
    current_filt_initialized = 0;
    overcurrent_samples = 0;
    peak_overcurrent_samples = 0;
}
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

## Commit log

2026-04-04 port to m2003 mcu
    [jlink.cfg, numicro_M23.cfg]
2026-04-05 encoder and commutation and protocol 2
2026-04-05 velocity loop
    [capture.csv]
2026-04-06 position loop
    [capture.csv]
2026-04-06 32 bit data types
    [capture.csv]
2026-04-06 fix direction change bug
    commutation updates immediately when commanded duty sign changes
    [capture.csv]
2026-04-06 mallet strike
    [capture.csv]
2026-04-06 adc oversampling
    and fix stale naming
    [app_adc.c, main.c, motor.c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]
2026-04-09 strike timing and pcb
    [interface.SLDASM, interface.SLDPRT, interface.step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]
2026-04-09 pcb dev
    [interface.kicad_pcb, interface.kicad_sch]
2026-04-10 calibration artifacts
    [home_offset_sweep.csv]
2026-04-11 midi player beginnings
    [capture.csv, strike_timing.csv]
2026-04-12 current loop
    [strike_timing.csv]
2026-04-12 interrupt based commutation
    [home_offset_sweep.csv, singlestrike.csv, strike_timing.csv]
2026-04-13 interface PCB layout
    [interface.kicad_pcb]
2026-04-14 interposer board
    [flexcircuit.kicad_pcb, flexcircuit.kicad_sch]
2026-04-14 flex circuit as ordered
    [flexcircuit.kicad_pcb]
2026-04-16 fix reversed connector
    and add a TVS diode
    [interface.kicad_pcb, interface.kicad_sch]
2026-04-18 BOD, adc and encoder faults
2026-04-18 adc priority
2026-04-18 clearer pcb labeling
    [interface.kicad_pcb]
2026-05-01 encoder polarity detection
2026-05-25 as-ordered V2 interface boards
    [interface.kicad_pcb, interface.kicad_sch]
2026-05-27 midi player api example
    [interface.kicad_pcb]
2026-07-31 docs update
    [actuator.SLDASM, base.SLDPRT, base.STEP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]
2026-07-31 Update actuator images and layout in README
    Rearranged actuator images and added a new image of the assembled actuator. Updated the layout of the connector and programming end section.
2026-08-08 mechanical parts refinement
    shallower base, magnet collar, full mechanical assembly document including the motor.
    [BL4825.SLDPRT, actuator.SLDASM, base.SLDPRT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]
2026-08-13 update for smaller actuator assembly
    [actuator.SLDASM, base.SLDPRT, magnet.SLDPRT]
2026-08-14 homing and strike bounds
2026-08-30 mechanical parts update
    [BL4825.SLDPRT, actuator.SLDASM, base.SLDPRT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]
2026-08-31 insert delay in chime backlogs
2026-09-20 pitch detection
2026-09-21 fix microphone tuning flow
2026-10-03 mechanical assembly update, completeness
    [93365A160_Brass Tapered Heat-Set Inserts for Plastic.SLDPRT, actuator.SLDASM, head.SLDPRT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]
2026-10-03 keep mallet settings visible and repeat slot colors
